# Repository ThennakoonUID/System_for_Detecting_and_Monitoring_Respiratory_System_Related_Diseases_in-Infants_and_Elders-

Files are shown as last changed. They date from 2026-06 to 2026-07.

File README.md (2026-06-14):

# VitaSync: Respiratory Disease Detection & Monitoring System

## Overview
**VitaSync** is an affordable, wearable monitoring system designed to detect and manage Chronic Respiratory Diseases (CRDs) such as Asthma, Chronic Obstructive Pulmonary Disease (COPD), and Sleep Apnea in infants and elders. Developed for the Engineering Design Project (BM1190) at the University of Moratuwa, this system shifts healthcare from reactive treatment to proactive management by providing continuous, non-invasive point-of-care data logging. 

## The Problem & Impact
Chronic Respiratory Diseases account for 12% of mortality in South Asia. Currently, early symptoms are frequently neglected in rural and low-income populations due to the centralization of high-cost diagnostic tools like hospital-grade spirometers. VitaSync addresses this critical diagnostic gap by offering a highly accessible, low-cost alternative that empowers patients and doctors to monitor conditions early and reliably.

## Key Features
* **Multiparameter Monitoring:** Continuously tracks $SpO_{2}$, heart rate, body temperature, and respiratory rate.
* **Physical Effort Tracking:** Utilizes an accelerometer to measure the physical expansion and contraction of the chest or neck to accurately log breathing rates.
* **Intelligent Analysis:** Implements a Machine Learning model to analyze raw sensor data, identify dangerous drops in oxygen levels, and detect early disease trends.
* **Mobile Dashboard:** Pairs with a mobile application to provide real-time visualization of "Respiration Status," "Oxygen Level," and "Breathing Rate" histories.
* **Emergency Alert System:** Triggers automated SMS alerts alongside real-time visual and audio warnings for necessary medical personnel or caretakers during critical events.

## Hardware Architecture
* **Microcontroller:** Low-cost ESP32-based processing unit.
* **Sensors:** High-sensitivity pulse oximetry module, heart-rate module, temperature sensor, and accelerometer.
* **Power Supply:** Rechargeable Li-Po battery system.
* **Form Factor:** Compact, battery-powered wearable wristband and chest strap ensuring patient comfort and ease of use.

## Project Team
**Team VitaSync** — Department of Electronic and Telecommunication Engineering (Biomedical Engineering), University of Moratuwa.
* Thennakoon U.I.D. (240657J)
* Pitiduwa S.M. (240518K)
* Tennekone A.D.T.M.S.H. (240642J)
* Wanninayaka W.M.I.R. (240695X)

## Hardware Architecture
* **Microcontroller:** Low-cost ESP32 or Arduino-based processing unit.
* **Sensors:** High-sensitivity pulse oximetry module, heart-rate module, temperature sensor, and accelerometer.
* **Power Supply:** Rechargeable Li-Po battery system.
* **Form Factor:** Compact, battery-powered wearable wristband and chest strap ensuring patient comfort and ease of use.

**Hardware Design Files:** [Click here to view and download the PCB design files from Google Drive](https://drive.google.com/drive/folders/1s421oYCiyX-rzGPese11IfVK0uFknzDo?usp=drive_link)

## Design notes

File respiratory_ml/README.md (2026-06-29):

# Respiratory Risk ML Model

A machine learning model that predicts whether a person is at risk of a respiratory disease by analysing SpO2 (blood oxygen saturation) and respiratory rate readings from a wearable device.

## Project overview

This model is part of the VitaSync wearable health monitoring system, built around an ESP32-WROOM-32 with a MAX30105 pulse oximeter and dual BMI160 IMUs.

The model is trained on the [BIDMC Respiratory Dataset](https://physionet.org/content/bidmc/1.0.0/) (53 ICU patients), using summary statistics extracted from 5-minute windows of SpO2 and RR readings.

## Model performance

- **Algorithm:** Logistic Regression
- **Cross-validation accuracy:** 95.3% ± 5.8%
- **Cross-validation recall:** 93.3% ± 13.3%
- **Cross-validation AUC-ROC:** 97.3% ± 5.3%
- **Training patients:** 42 | **Test patients:** 11

## Risk label definition

A patient is flagged **at risk** if any of the following are true over a 5-minute window:
- Mean SpO2 < 95%
- Minimum SpO2 < 92%
- Mean respiratory rate > 20 breaths/min
- More than 20% of RR readings outside the normal 12–20 bpm range

## Setup

1. Clone the repository
2. Create a virtual environment: `python3 -m venv venv && source venv/bin/activate`
3. Install dependencies: `pip install -r requirements.txt`
4. Run notebooks in order to reproduce the model

## Dataset

BIDMC Waveform and Physiologic Signal Collection (PhysioNet).
Raw dataset files are not included — run `01_download.ipynb` to download them.

## Disclaimer

Research prototype only. Not a certified medical device.

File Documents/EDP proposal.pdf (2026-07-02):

### Department of Electronic and Telecommunication

### Engineering

## (Biomedical Engineering)

## University of Moratuwa

# Team VitaSync

## System for Detecting and Monitoring Respiratory System Related Diseases in Infants and Elders

## Project Proposal

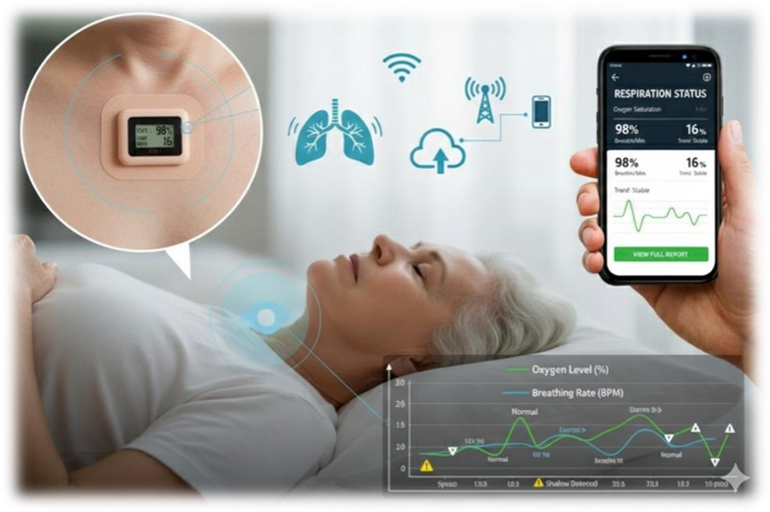
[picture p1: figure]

## Engineering Design Project – BM1190

Name | Index Number
Thennakoon U.I.D. | 240657J
Pitiduwa S.M. | 240518K
Tennekone A.D.T.M.S.H. | 240642J
Wanninayaka W.M.I.R. | 240695X

Problem Statement

Chronic Respiratory Diseases (CRDs) account for 12% of deaths in South Asia¹
. While early
detection significantly improves outcomes, a critical gap exists in accessible, low-cost diagnostic and monitoring technology. Current clinical tools are often centralized in urban hospitals, leading to the neglect of early symptoms in rural and low-income populations and resulting in preventable mortality.

Justification of Problem Selection

Selection of Chronic Respiratory Diseases (CRD) such as Chronic Obstructive Pulmonary Disease (COPD), Asthma and Sleep Apnea management in South Asia as a design focus is justified by the critical diagnostic gap that currently contributes to 12% of regional mortality

1
While these diseases are manageable if detected early, the current medical infrastructure relies heavily on centralized, high-cost diagnostic tools such as hospital grade spirometers that are inaccessible to the rural majority. This creates a technical failure where early signs are neglected not just due to a lack of awareness, but due to a lack of affordable, point-of-care monitoring technology. From an engineering perspective, there is a clear demand for a portable and affordable solution that can provide consistent, non-invasive data logging. By automating the monitoring process, a design intervention can shift the healthcare model from “reactive treatment” of the worst possible outcomes to “proactive management” during early stages, reducing the disease burden and associated productivity loss.

Proposed Solution

A wearable wrist band and chest strap powered by battery (Li-Po battery) that measures SpO2 and heart rate using a high sensitivity pulse oximetry and heart-rate module along with respiratory rate/breathing effort using an accelerometer and temperature using a temperature sensing module. Different respiratory diseases such as Asthma, COPD and sleep apnea show different levels of drops in Oxygen. Respiratory rate is tracked by measuring the physical expansion and contraction of the chest or neck. Raw data is collected using these sensors using a relatively low cost ESP32 or Arduino-based system. A Machine Learning model is then implemented to analyze the data, detect trends and alert the necessary personnel via an emergency SMS alert and real time visual and audio warnings. System should be implemented using low cost hardware and compact ensuring ease of use.

References

[1] World Health Organization - Chronic respiratory diseases in WHO South-East Asia – World Health Organization[Online] - Chronic respiratory diseases in WHO South-East Asia.pdf (https://knowledge-action-portal.com/sites/default/files/2025-09/Chronic%20respiratory%20diseases%20in%20WHO%20South-East%20Asia.pdf)

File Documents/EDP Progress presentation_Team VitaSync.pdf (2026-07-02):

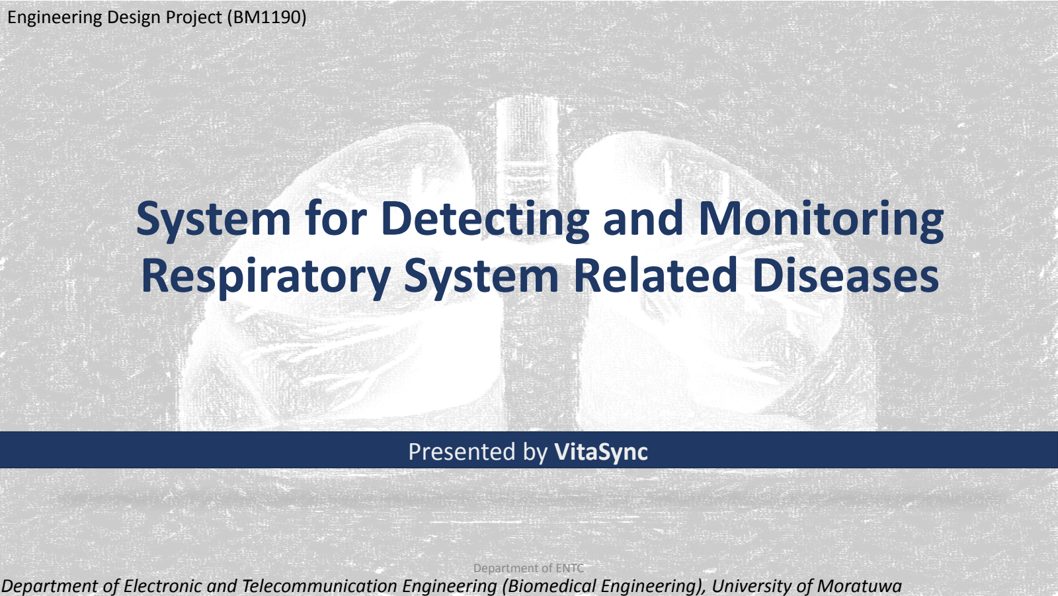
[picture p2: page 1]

# System for Detecting and Monitoring Respiratory System Related Diseases

Department of Electronic and Telecommunication Engineering (Biomedical Engineering), University of Moratuwa

## Presented by VitaSync

Engineering Design Project (BM1190)

Department of ENTC

# Team Members

U.I.D. Thennakoon

S.M. Pitiduwa

A.D.T.M.S.H. Tennekone

W.M.I.R. Wanninayaka

240518K

240657J

240642J

240695X

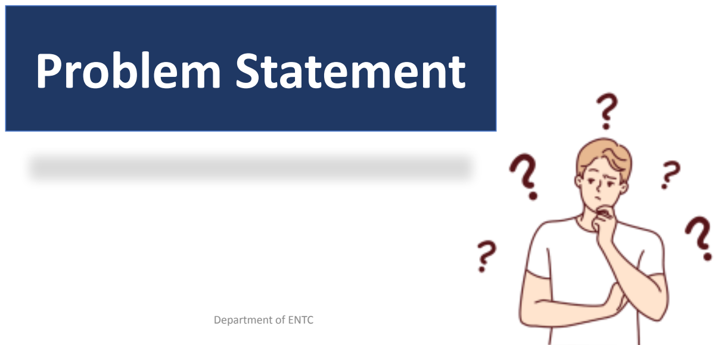
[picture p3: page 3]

# Problem Statement

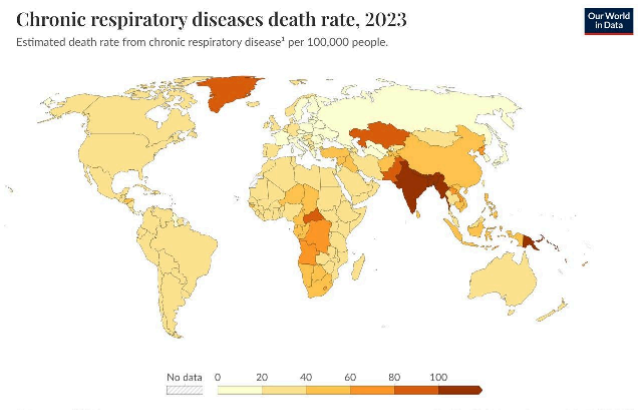
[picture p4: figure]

- The Statistic: Chronic respiratory diseases (CRDs) – primarily chronic obstructive pulmonary disease (COPD) and asthma – are a major and growing public health challenge in the WHO South-East Asia Region, responsible for nearly 12% of all deaths WHO Link
- The Gap: A critical lack of accessible, low-cost diagnostic and monitoring
technology.
- The Constraint: Current tools are centralized in urban hospitals, leading to the neglect of early
symptoms in rural populations

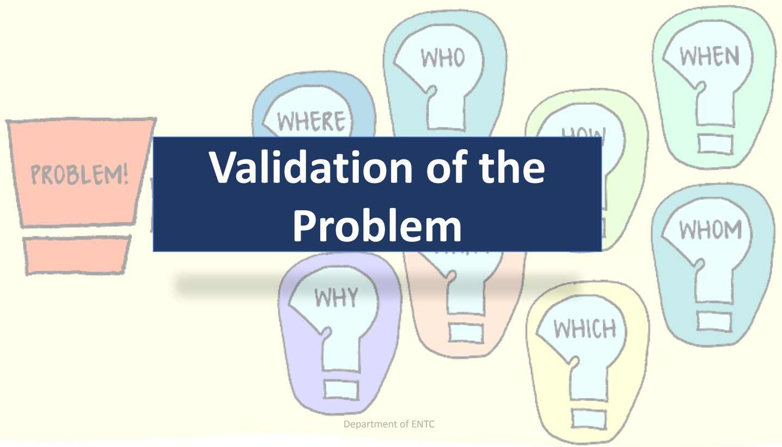
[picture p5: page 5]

# Validation of the Problem

Evidence: Hospital-grade spirometers are high-cost and inaccessible to the rural majority.

Technical Failure: Early signs are missed not just due to lack of awareness, but due to a lack of

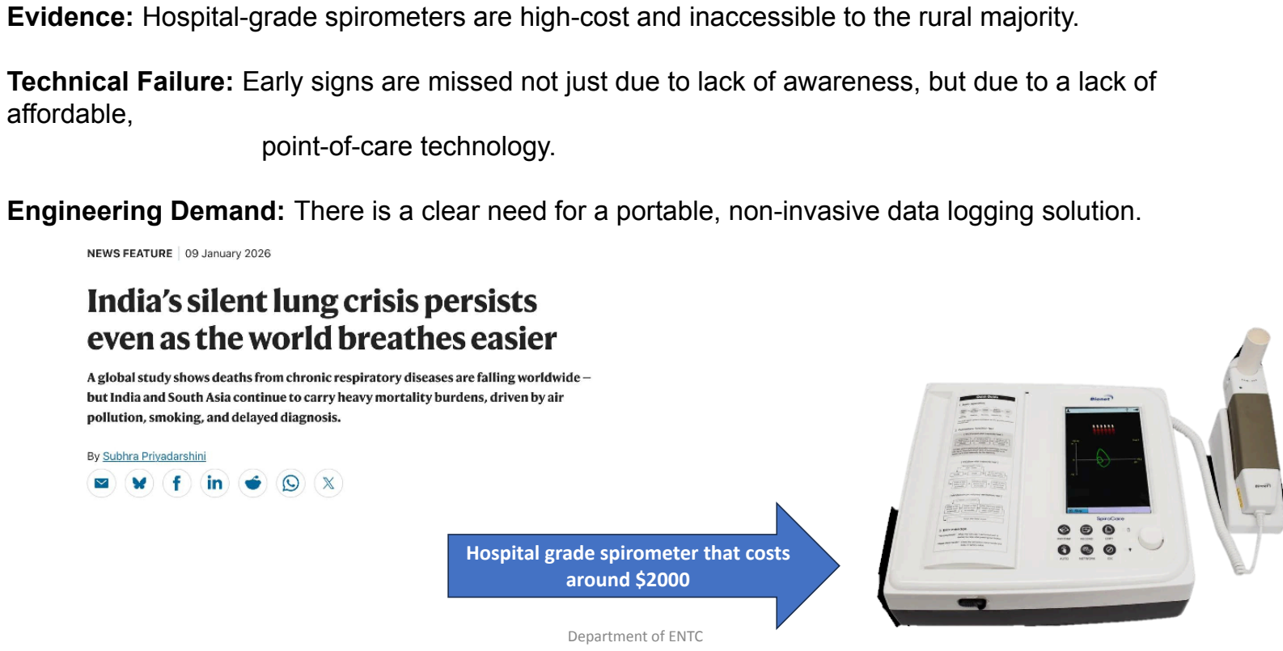
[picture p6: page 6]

affordable,
point-of-care technology.

Engineering Demand: There is a clear need for a portable, non-invasive data logging solution.

Hospital grade spirometer that costs around $2000

- Discussed the need for a non-invasive monitoring device with multiple resource personnel associated with the medical field.
- Dr. Sanjeewa Tennekone - Consultant Neonatologist - 0773645577
- Dr. Dilrukshi Maheshika - Consultant Rheumatologist - 0773417558
- Dr. P.L.B.Nishantha - MO Cardiothoracic - 0776552891
- Dr. Dammika Fernando - MO Radiology - 0777499150
- Dr. S.A.P.L.Nanayakkara - 0772619993

# Our Solution

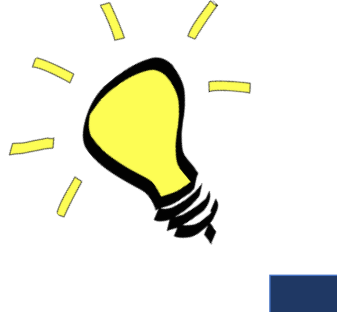
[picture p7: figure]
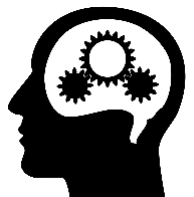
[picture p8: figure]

PCB

Breathing pattern
identification using MPU 5060 three axis accelerometer

SPO2 level and BPM
MAX30102 readings

ML model
trained
using
existing
datasets
Power

Notification if disease is detected or not

Probability of disease

Physical indicators

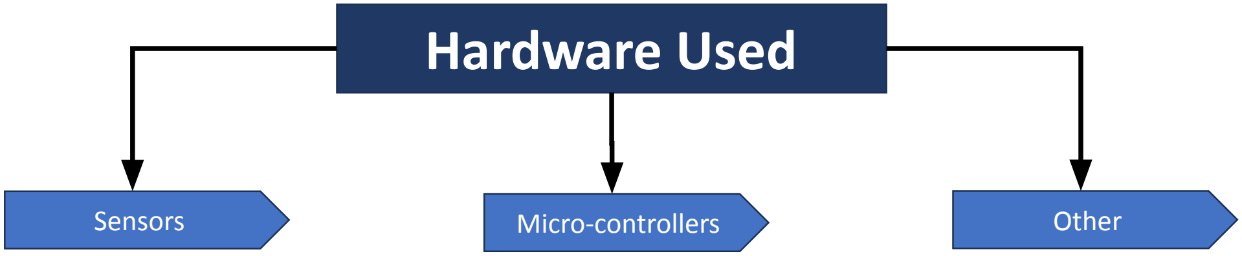
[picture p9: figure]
Hardware Used; Sensors; Micro-controllers; Other
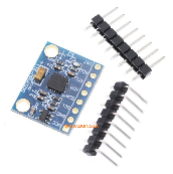
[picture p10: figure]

MAX30102

MPU 6050 3-Axis
Accelerometer

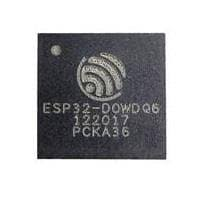
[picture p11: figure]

Resistors
Capacitors
Voltage regulators
DC-DC Boost converters
Charging modules

ATmega328P-AU

ESP32 DOWDQ6
(To run the ML model)

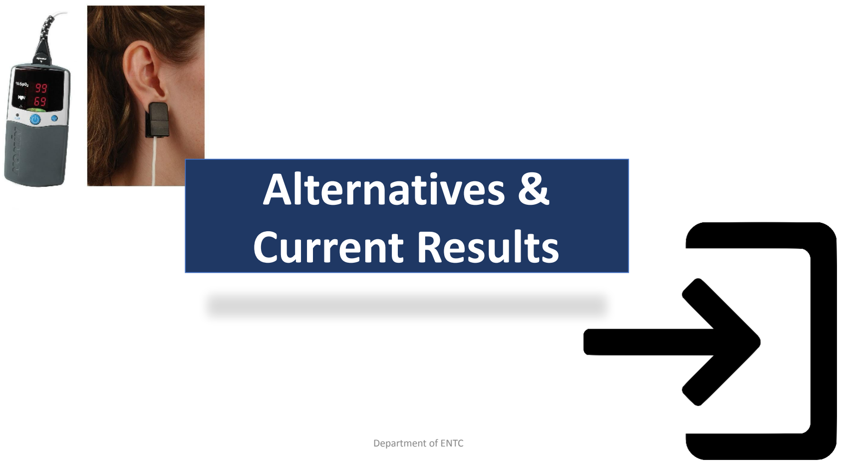
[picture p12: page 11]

# Alternatives & Current Results

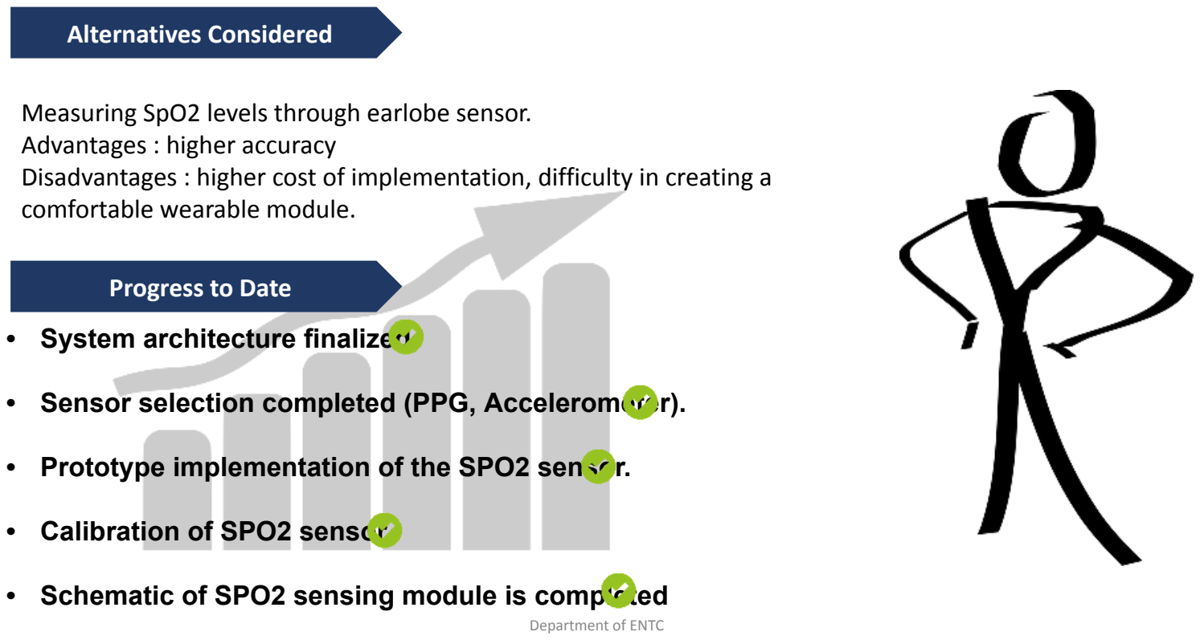
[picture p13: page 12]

Measuring SpO2 levels through earlobe sensor.
Advantages : higher accuracy
Disadvantages : higher cost of implementation, difficulty in creating a comfortable wearable module.
- System architecture finalized.
- Sensor selection completed (PPG, Accelerometer).
- Prototype implementation of the SPO2 sensor.
- Calibration of SPO2 sensor.

## - Schematic of SPO2 sensing module is completed

Progress to Date

Alternatives Considered

# Challenges & Overcoming Them

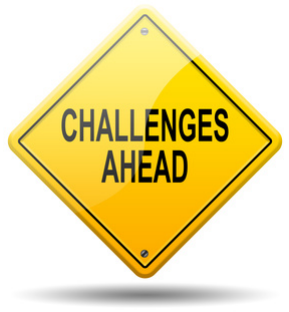
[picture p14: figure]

Problem | Current solution
Amount of noise due to the distances from the sensor modules to the control unit and other noise related to the sensors are high. | Use a cable that can transmit sensor readings with less accumulation of noise (shielded 4-core wire). However, wearbility issues might occur. Use digital filtering methods.
Creating enclosures for sensor modules that are comfortable to wear for users. | Use stretchable and elastic-like materials that are easy to wear.
Collecting data to train a ML model. | Use existing datasets that can be found on the internet.
Obtaining accurate readings from sensors. | Calibrate the sensors properly use digital filtering methods to remove noise.
Displaying the data and predictions to users. | Create a simple dashboard that can display readings and user information.

# Thank you !

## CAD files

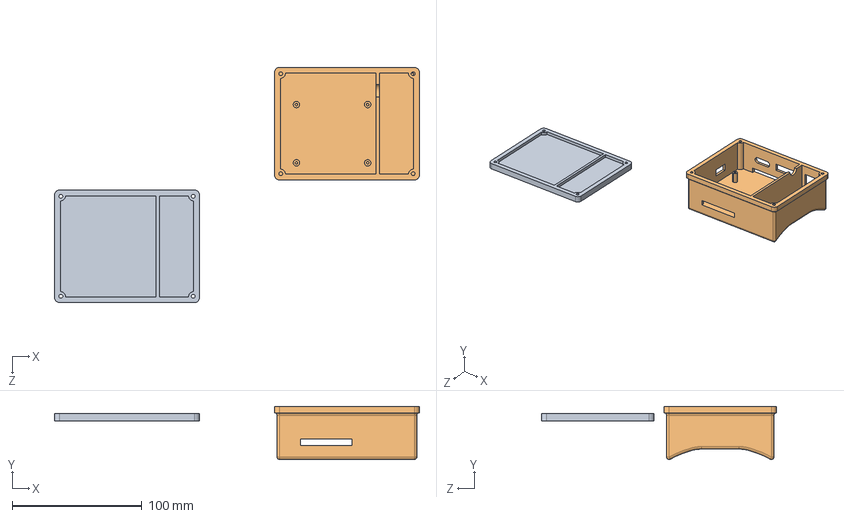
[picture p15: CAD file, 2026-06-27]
Enclosures/STEP_files/Shoulder_Assembly.STEP
281.8 x 41.1 x 181.6 mm
lid
part final

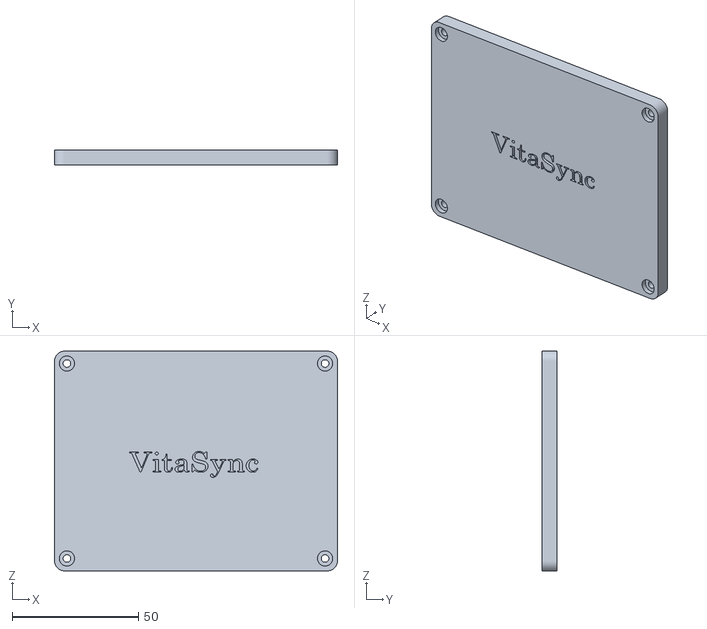
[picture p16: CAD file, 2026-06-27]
Enclosures/STL_files/Shoulder_Assembly - Lid-1.STL
112.0 x 6.00 x 87.0

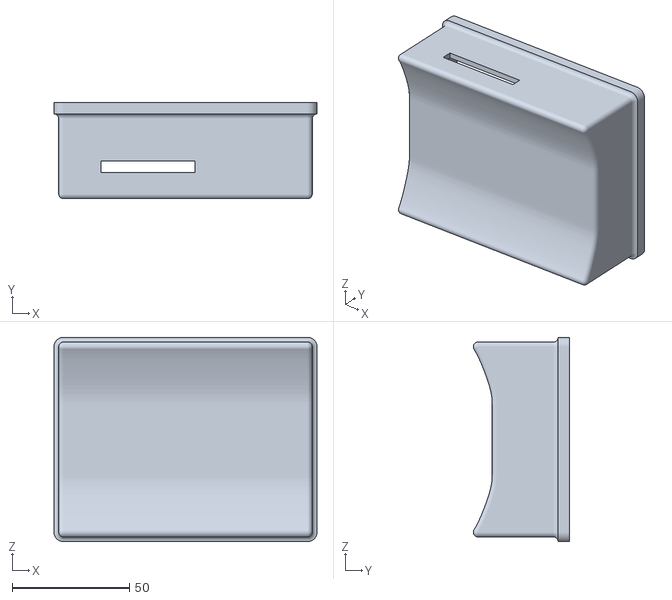
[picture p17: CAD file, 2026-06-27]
Enclosures/STL_files/Shoulder_Assembly - Enclosure.STL
112.0 x 41.1 x 87.0

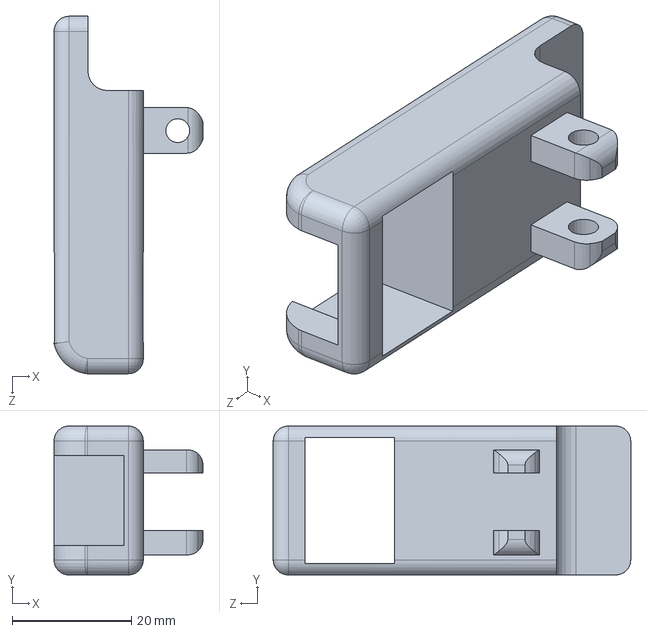
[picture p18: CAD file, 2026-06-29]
Enclosures/Solidworks_part_files/finger tip bellow part.SLDPRT
25.0 x 25.0 x 60.0 mm

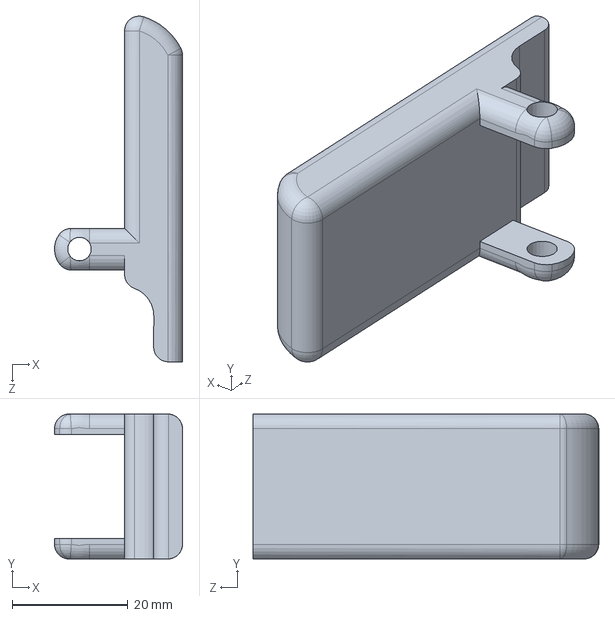
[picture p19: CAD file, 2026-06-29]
Enclosures/Solidworks_part_files/finger tip upper part.SLDPRT
22.1 x 25.0 x 59.6 mm

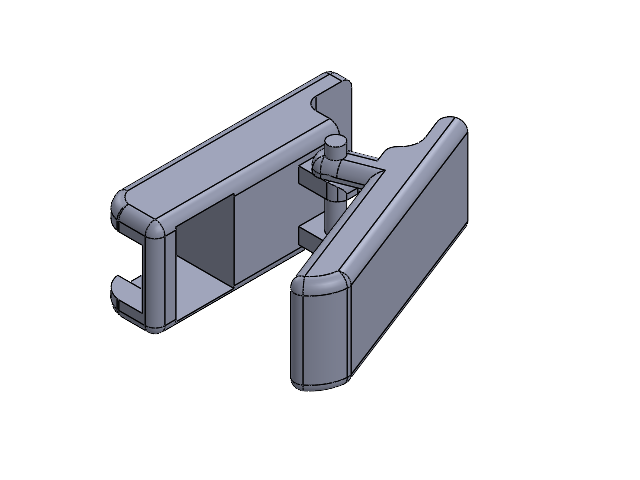
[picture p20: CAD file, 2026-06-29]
Enclosures/Assembly_files/Fingertip_Assembly.SLDASM
bellow part
nut

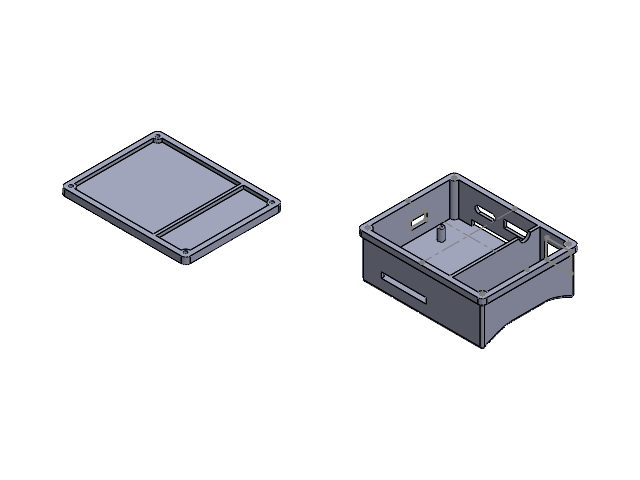
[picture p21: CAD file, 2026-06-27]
Enclosures/Assembly_files/Shoulder_Assembly.SLDASM
lid
part final

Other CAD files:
Enclosures/Solidworks_part_files/Lid.SLDPRT
Enclosures/Solidworks_part_files/Enclosure.SLDPRT

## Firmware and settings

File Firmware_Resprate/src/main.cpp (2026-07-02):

#include <Arduino.h>
#include <Wire.h>
#include <DFRobot_BMI160.h>
#include <WiFi.h>
#include <FirebaseESP32.h>
#include <esp_task_wdt.h>

// =============================================================
//  WIFI & FIREBASE CONFIGURATION
// =============================================================
#define WIFI_SSID "Your WiFi SSID"
#define WIFI_PASSWORD "Your WiFi Password"

#define FIREBASE_HOST "respiratory-system-monitor-default-rtdb.firebaseio.com"
#define FIREBASE_AUTH "Firebase Database Secret or API Key"

FirebaseData fbdo;
FirebaseAuth auth;
FirebaseConfig config;
TaskHandle_t FirebaseTaskHandle;

// =============================================================
//  SENSOR CONFIGURATION
// =============================================================
#define I2C_SDA 21
#define I2C_SCL 22

#define ADDR_CHEST 0x68 // Primary Abdomen Sensor
#define ADDR_BACK  0x69 // Reference Back Sensor

#define SAMPLE_RATE_HZ  25
#define SAMPLE_INTERVAL (1000 / SAMPLE_RATE_HZ)

// ── Motion Gating ─────────────────────────────────────────
#define MOTION_THRESHOLD  800.0f 
#define MOTION_LOCKOUT_MS 3000

#define PRINT_INTERVAL    1000

// CRITICAL FIX: Turn off 25Hz raw data printing to prevent UART overflow
// and garbled text while running standalone over WiFi.
#define ENABLE_TELEPLOT   0 

// =============================================================
//  POWER / WIFI STABILITY SETTINGS
// =============================================================
// If your PCB power rail cannot supply full peak current, lowering
// TX power reduces current spikes that cause brownout resets.
// 0 = auto/full power (try this first once hardware power is fixed),
// or use WIFI_POWER_15dBm / WIFI_POWER_11dBm to cut peak draw.
#define REDUCE_WIFI_TX_POWER 1

#define WIFI_RECONNECT_INTERVAL_MS 5000
#define FIREBASE_RETRY_INTERVAL_MS 3000

// How often the status fields (state, progress %, uptime, etc.) get pushed
// to Firebase. Kept separate from the 2s rate/motion upload cadence since
// status changes less often and we don't want to spam the DB.
#define STATUS_UPLOAD_INTERVAL_MS 2000

// =============================================================
//  SYSTEM STATUS TRACKING (for Firebase progress reporting)
// =============================================================
enum SystemState {
  STATE_BOOTING,           // setup() running
  STATE_WIFI_CONNECTING,   // waiting for WiFi
  STATE_SENSOR_INIT,       // initializing BMI160s
  STATE_SENSOR_FAILED,     // sensor init failed, retrying in background
  STATE_GATHERING_WINDOW,  // running, peak-detection buffer still filling
  STATE_RUNNING,           // fully operational, RR values valid
  STATE_MOTION_GATED       // running but currently motion-gated
};

const char* stateToString(SystemState s) {
  switch (s) {
    case STATE_BOOTING:          return "booting";
    case STATE_WIFI_CONNECTING:  return "wifi_connecting";
    case STATE_SENSOR_INIT:      return "sensor_init";
    case STATE_SENSOR_FAILED:    return "sensor_failed";
    case STATE_GATHERING_WINDOW: return "gathering_window";
    case STATE_RUNNING:          return "running";
    case STATE_MOTION_GATED:     return "motion_gated";
    default:                     return "unknown";
  }
}

volatile SystemState systemState = STATE_BOOTING;
volatile int windowProgressPercent = 0; // 0-100, how full the RR peak-detection buffer is

// =============================================================
//  BIQUAD STRUCT (Base element for filters)
// =============================================================
struct Biquad {
  float b0, b1, b2, a1, a2;
  float x1 = 0, x2 = 0, y1 = 0, y2 = 0;
  
  Biquad(float _b0, float _b1, float _b2, float _a1, float _a2)
      : b0(_b0), b1(_b1), b2(_b2), a1(_a1), a2(_a2) {}

  float process(float x) {
    float y = b0*x + b1*x1 + b2*x2 - a1*y1 - a2*y2;
    x2 = x1; x1 = x;
    y2 = y1; y1 = y;
    return y;
  }
  void reset() { x1=x2=y1=y2=0; }
};

// =============================================================
//  STAGE 1: 6th-Order Butterworth BP + Notch + Savitzky-Golay
// =============================================================
struct BPFilter6 {
  Biquad s1 = Biquad( 0.00057f,  0.00000f, -0.00057f, -1.98942f,  0.98944f);
  Biquad s2 = Biquad( 0.00057f,  0.00000f, -0.00057f, -1.97128f,  0.97290f);
  Biquad s3 = Biquad( 0.00057f,  0.00000f, -0.00057f, -1.95524f,  0.95810f);
  
  float process(float x) { return s3.process(s2.process(s1.process(x))); }
  void reset() { s1.reset(); s2.reset(); s3.reset(); }
};

struct NotchFilter1Hz {
  Biquad s1 = Biquad( 0.97546f, -1.89505f,  0.97546f, -1.89505f,  0.95091f);
  float process(float x) { return s1.process(x); }
  void reset() { s1.reset(); }
};

constexpr int SG_WIN = 11;
constexpr float SG_COEF[SG_WIN] = {
    -0.09090909f,  0.06060606f,  0.16883117f,  0.23376623f,  0.25541126f,
     0.23376623f,  0.16883117f,  0.06060606f, -0.09090909f, -0.06060606f,
    -0.09090909f
};

struct SavitzkyGolay {
  static const int WIN = SG_WIN;
  float buf[WIN] = {};
  int   head = 0;
  int   filled = 0;
  
  float process(float x) {
    buf[head] = x;
    head = (head + 1) % WIN;
    if (filled < WIN) { filled++; }
    if (filled < WIN) return x; 

    float out = 0.0f;
    for (int i = 0; i < WIN; i++) {
      int idx = (head + i) % WIN; 
      out += SG_COEF[i] * buf[idx];
    }
    return out;
  }

  void reset() {
    for (int i = 0; i < WIN; i++) buf[i] = 0;
    head = 0; filled = 0;
  }
};

// =============================================================
//  STAGE 2: Time-Domain Peak Detection (Sliding Window)
// =============================================================
struct PeakDetectionRR {
  static const int BUF_LEN      = 300; 
  static const int UPDATE_EVERY = 25; 
  static const int MIN_DIST     = 20; 

  float buf[BUF_LEN] = {};
  int   head = 0;
  bool  full = false;
  int   samplesSinceUpdate = 0;
  float lastRR = 0.0f;

  void push(float v) {
    buf[head] = v;
    head = (head + 1) % BUF_LEN;
    if (!full && head == 0) full = true;
    samplesSinceUpdate++;
  }

  float compute() {
    if (!full) return 0.0f; 
    if (samplesSinceUpdate < UPDATE_EVERY) return lastRR; 
    
    samplesSinceUpdate = 0; 

    float win[BUF_LEN];
    float mean = 0;
    for (int i = 0; i < BUF_LEN; i++) {
      win[i] = buf[(head + i) % BUF_LEN];
      mean += win[i];
    }
    mean /= BUF_LEN; 

    int peakIndices[50]; 
    int peakCount = 0;
    
    for (int i = 1; i < BUF_LEN - 1; i++) {
      if (win[i] > win[i - 1] && win[i] > win[i + 1] && win[i] > mean) {
        if (peakCount == 0 || (i - peakIndices[peakCount - 1]) >= MIN_DIST) {
          peakIndices[peakCount++] = i;
          if (peakCount >= 50) break; 
        } 
        else if (win[i] > win[peakIndices[peakCount - 1]]) {
          peakIndices[peakCount - 1] = i;
        }
      }
    }

    if (peakCount >= 2) {
      float totalIntervals = 0;
      for (int i = 1; i < peakCount; i++) {
        totalIntervals += (peakIndices[i] - peakIndices[i - 1]);
      }
      
      float avgIntervalSamples = totalIntervals / (peakCount - 1);
      float avgIntervalSeconds = avgIntervalSamples / (float)SAMPLE_RATE_HZ; 
      float newRR = 60.0f / avgIntervalSeconds;
      
      if (newRR >= 4.0f && newRR <= 60.0f) {
         lastRR = (lastRR == 0.0f) ? newRR : (0.4f * newRR + 0.6f * lastRR);
      }
    }
    return lastRR;
  }

  void reset() {
    for (int i = 0; i < BUF_LEN; i++) buf[i] = 0;
    head = 0; full = false; samplesSinceUpdate = 0; lastRR = 0;
  }
};

// =============================================================
//  MEDIAN FILTER
// =============================================================
struct MedianFilter {
  static const int SZ = 9;
  float buf[SZ] = {};
  int   idx = 0;

  float process(float v) {
    buf[idx] = v;
    idx = (idx + 1) % SZ;
    float s[SZ];
    for (int i = 0; i < SZ; i++) s[i] = buf[i];
    for (int i = 1; i < SZ; i++) {
      float key = s[i];
      int j = i - 1;
      while (j >= 0 && s[j] > key) { s[j+1] = s[j]; j--; }
      s[j+1] = key;
    }
    return s[SZ / 2];
  }
};

// =============================================================
//  MULTI-AXIS DIFFERENTIAL FUSION
// =============================================================
struct AxisFuser {
  static const int WIN = 50;
  float buf[WIN] = {};
  int   idx = 0;
  bool  full = false;
  float variance = 0;
  
  void push(float v) {
    buf[idx] = v;
    idx = (idx + 1) % WIN;
    if (idx == 0) full = true;
    int n = full ? WIN : idx;
    if (n < 2) { variance = 0; return; }
    float mean = 0;
    for (int i = 0; i < n; i++) mean += buf[i];
    mean /= n;
    float var = 0;
    for (int i = 0; i < n; i++) var += (buf[i]-mean)*(buf[i]-mean);
    variance = var / n;
  }
};

float fusedDiff(float dx, float dy, float dz, float vx, float vy, float vz) {
  float total = vx + vy + vz;
  if (total < 1e-9f) return (dx + dy + dz) / 3.0f;  
  return (dx*vx + dy*vy + dz*vz) / total;
}

// =============================================================
//  GLOBALS & INSTANCES
// =============================================================
DFRobot_BMI160 bmi_chest, bmi_back;
bool bmiReady = false;

MedianFilter    med_cx, med_cy, med_cz;   
MedianFilter    med_bx, med_by, med_bz;
BPFilter6       bp_cx, bp_cy, bp_cz;
BPFilter6       bp_bx, bp_by, bp_bz;
NotchFilter1Hz  notch;
SavitzkyGolay   sgSmooth;            
PeakDetectionRR pdRR; 

AxisFuser fuser_cx, fuser_cy, fuser_cz;
AxisFuser fuser_bx, fuser_by, fuser_bz;

volatile float respiratoryRate  = 0.0f;
volatile bool  motionGated    = false;

unsigned long lastMotionTime = 0;
unsigned long lastRRSample   = 0;
unsigned long lastPrint      = 0;

// WiFi/Firebase state tracking (non-blocking)
volatile bool wifiWasConnected = false;
unsigned long lastWifiAttempt = 0;
bool firebaseConfigured = false;

// =============================================================
//  WIFI EVENT HANDLER (event-driven, no blocking loops)
// =============================================================
void onWifiEvent(WiFiEvent_t event) {
  switch (event) {
    case ARDUINO_EVENT_WIFI_STA_CONNECTED:
      Serial.println("[WiFi] Connected to AP.");
      break;
    case ARDUINO_EVENT_WIFI_STA_GOT_IP:
      Serial.print("[WiFi] Got IP: ");
      Serial.println(WiFi.localIP());
      wifiWasConnected = true;
      break;
    case ARDUINO_EVENT_WIFI_STA_DISCONNECTED:
      Serial.println("[WiFi] Disconnected. Will retry in background.");
      wifiWasConnected = false;
      break;
    default:
      break;
  }
}

// Call periodically from loop() — non-blocking reconnect attempt.
void maintainWifi() {
  if (WiFi.status() == WL_CONNECTED) return;
  unsigned long now = millis();
  if (now - lastWifiAttempt < WIFI_RECONNECT_INTERVAL_MS) return;
  lastWifiAttempt = now;
  Serial.println("[WiFi] Attempting reconnect...");
  WiFi.disconnect();
  WiFi.begin(WIFI_SSID, WIFI_PASSWORD);
}

// =============================================================
//  CORE 0: FIREBASE UPLOAD TASK (STANDALONE PROOF)
// =============================================================
void firebaseUploadTask(void *pvParameters) {
  esp_task_wdt_add(NULL); // register this task with the watchdog
  unsigned long lastStatusUpload = 0;

  for (;;) {
    esp_task_wdt_reset();

    // Only upload if properly connected and authenticated.
    // This never blocks the sensor loop on core 1.
    if (WiFi.status() == WL_CONNECTED && Firebase.ready()) {
      bool ok1 = Firebase.setFloat(fbdo, "/respiratory_data/rate", respiratoryRate);
      esp_task_wdt_reset(); // feed the watchdog immediately after this blocking call
      if (!ok1) {
        Serial.print("[Firebase] setFloat failed: ");
        Serial.println(fbdo.errorReason());
      }

      bool ok2 = Firebase.setBool(fbdo, "/respiratory_data/motion_gated", motionGated);
      esp_task_wdt_reset(); // feed the watchdog immediately after this blocking call
      if (!ok2) {
        Serial.print("[Firebase] setBool failed: ");
        Serial.println(fbdo.errorReason());
      }

      // Status/progress fields — uploaded less frequently since they
      // change slower than rate/motion, to keep this loop iteration short.
      unsigned long now = millis();
      if (now - lastStatusUpload >= STATUS_UPLOAD_INTERVAL_MS) {
        lastStatusUpload = now;

        Firebase.setString(fbdo, "/respiratory_data/status/state", stateToString(systemState));
        esp_task_wdt_reset();

        Firebase.setInt(fbdo, "/respiratory_data/status/window_progress_percent", windowProgressPercent);
        esp_task_wdt_reset();

        Firebase.setBool(fbdo, "/respiratory_data/status/wifi_connected", WiFi.status() == WL_CONNECTED);
        esp_task_wdt_reset();

        Firebase.setBool(fbdo, "/respiratory_data/status/sensors_ready", bmiReady);
        esp_task_wdt_reset();

        Firebase.setInt(fbdo, "/respiratory_data/status/uptime_seconds", (int)(millis() / 1000));
        esp_task_wdt_reset();

        Firebase.setInt(fbdo, "/respiratory_data/status/wifi_rssi", WiFi.status() == WL_CONNECTED ? WiFi.RSSI() : 0);
        esp_task_wdt_reset();
      }
    }

    // Generous delay prevents WDT crash and network stack overflow
    vTaskDelay(pdMS_TO_TICKS(2000));
  }
}

// =============================================================
//  UPDATE BMI160
// =============================================================
void updateBMI160() {
  unsigned long now = millis();
  if (now - lastRRSample < SAMPLE_INTERVAL) return;
  lastRRSample = now;

  int16_t dc[6] = {}, db[6] = {};
  if (bmi_chest.getAccelGyroData(dc) != 0) return;
  if (bmi_back.getAccelGyroData(db)  != 0) return;
  
  float cxr = (dc[3]/16384.0f) * 1000.0f;
  float cyr = (dc[4]/16384.0f) * 1000.0f;
  float czr = (dc[5]/16384.0f) * 1000.0f;
  
  float bxr = (db[3]/16384.0f) * 1000.0f;
  float byr = (db[4]/16384.0f) * 1000.0f;
  float bzr = (db[5]/16384.0f) * 1000.0f;

  float cx_g = cxr/1000.0f; float cy_g = cyr/1000.0f; float cz_g = czr/1000.0f;
  float bx_g = bxr/1000.0f; float by_g = byr/1000.0f; float bz_g = bzr/1000.0f;

  float magChest = sqrtf(cx_g*cx_g + cy_g*cy_g + cz_g*cz_g);
  float magBack  = sqrtf(bx_g*bx_g + by_g*by_g + bz_g*bz_g);
  
  if (magChest < 0.1f || magBack < 0.1f) return;

  float instMotionChest = fabsf(magChest - 1.0f) * 1000.0f;
  float instMotionBack  = fabsf(magBack - 1.0f) * 1000.0f;
  float motionMag = fmaxf(instMotionChest, instMotionBack);
  
  if (motionMag > MOTION_THRESHOLD) {
    motionGated = true; lastMotionTime = now;
    bp_cx.reset(); bp_cy.reset(); bp_cz.reset();
    bp_bx.reset(); bp_by.reset(); bp_bz.reset();
    notch.reset(); sgSmooth.reset(); pdRR.reset();
  }
  
  if (motionGated && now - lastMotionTime > MOTION_LOCKOUT_MS) motionGated = false;
  
  float cx = med_cx.process(cxr), cy = med_cy.process(cyr), cz = med_cz.process(czr);
  float bx = med_bx.process(bxr), by = med_by.process(byr), bz = med_bz.process(bzr);
  
  float fcx = bp_cx.process(cx), fcy = bp_cy.process(cy), fcz = bp_cz.process(cz);
  float fbx = bp_bx.process(bx), fby = bp_by.process(by), fbz = bp_bz.process(bz);
  
  float dx = fcx - fbx, dy = fcy - fby, dz = fcz - fbz;
  fuser_cx.push(fcx); fuser_cy.push(fcy); fuser_cz.push(fcz);
  fuser_bx.push(fbx); fuser_by.push(fby); fuser_bz.push(fbz);

  float vx = (fuser_cx.variance + fuser_bx.variance);
  float vy = (fuser_cy.variance + fuser_by.variance);
  float vz = (fuser_cz.variance + fuser_bz.variance);
  
  float diff_fused = fusedDiff(dx, dy, dz, vx, vy, vz);
  
  float notched = notch.process(diff_fused);
  float sig     = sgSmooth.process(notched);
  
  if (!motionGated) {
    pdRR.push(sig);
    float rr = pdRR.compute();
    if (rr > 0) respiratoryRate = rr;
  }

  // ── Status tracking for Firebase progress reporting ──
  if (motionGated) {
    systemState = STATE_MOTION_GATED;
  } else if (!pdRR.full) {
    systemState = STATE_GATHERING_WINDOW;
    windowProgressPercent = (pdRR.samplesSinceUpdate * 100) / PeakDetectionRR::BUF_LEN;
  } else {
    systemState = STATE_RUNNING;
    windowProgressPercent = 100;
  }

#if ENABLE_TELEPLOT
  Serial.print(">SigFused_mg:");  Serial.println(sig, 2);
  Serial.print(">Motion_mg:");    Serial.println(motionMag, 1);
  Serial.print(">Gated:");        Serial.println(motionGated ? 10 : 0);
  Serial.print(">RespRate:");     Serial.println(respiratoryRate, 1);
#endif
}

void printStatus() {
  if (millis() - lastPrint < PRINT_INTERVAL) return;
  lastPrint = millis();

  Serial.print("State=");
  Serial.print(stateToString(systemState));
  Serial.print(" Progress=");
  Serial.print(windowProgressPercent);
  Serial.println("%");

  Serial.print("RespRate=");
  if (!pdRR.full) {
    int percent = (pdRR.samplesSinceUpdate * 100) / PeakDetectionRR::BUF_LEN;
    Serial.print("Gathering window ("); Serial.print(percent); Serial.println("%)");
  } else {
    Serial.print(respiratoryRate, 1); Serial.println(" br/min");
  }
  Serial.print("WiFi=");
  Serial.println(WiFi.status() == WL_CONNECTED ? "connected" : "DISCONNECTED");
}

// =============================================================
//  SETUP
// =============================================================
void setup() {
  Serial.begin(115200);
  delay(1500); // let power rails stabilize before WiFi radio init (helps with brownout on marginal supplies)
  Serial.println("\nBooting Standalone System...");
  systemState = STATE_BOOTING;

  // Configure watchdog for the whole app. 20s gives headroom for a slow
  // Firebase/SSL call (bounded to ~4s read timeout, see setup() below)
  // plus WiFi reconnect attempts, without masking a genuine hang.
  esp_task_wdt_init(20, true);

  // 1. Initialize Wi-Fi (event-driven, non-blocking after this point)
  systemState = STATE_WIFI_CONNECTING;
  WiFi.onEvent(onWifiEvent);
  WiFi.mode(WIFI_STA);
  WiFi.setAutoReconnect(true);
  WiFi.persistent(false); // avoid unnecessary flash writes on every connect

#if REDUCE_WIFI_TX_POWER
  // Lowering TX power reduces peak current draw, which helps a lot if the
  // 3.3V rail is marginal. Remove/raise this once hardware power is solid.
  WiFi.begin(WIFI_SSID, WIFI_PASSWORD);
  WiFi.setTxPower(WIFI_POWER_15dBm);
#else
  WiFi.begin(WIFI_SSID, WIFI_PASSWORD);
#endif

  // Short bounded wait just so first boot has a chance to come up before
  // we start sensors — but we DO NOT hang forever like the old code did.
  unsigned long wifiStart = millis();
  while (WiFi.status() != WL_CONNECTED && millis() - wifiStart < 8000) {
    delay(250);
    Serial.print(".");
  }
  Serial.println();
  if (WiFi.status() == WL_CONNECTED) {
    Serial.println("Wi-Fi connected on boot.");
  } else {
    Serial.println("Wi-Fi not yet connected — will keep retrying in background.");
  }

  // 2. Initialize Firebase
  fbdo.setBSSLBufferSize(1024, 512); // CRITICAL FIX: Optimize SSL memory
  config.database_url = FIREBASE_HOST;
  config.signer.tokens.legacy_token = FIREBASE_AUTH;
  Firebase.reconnectWiFi(true);

  // Bound how long a single Firebase call is allowed to block. Without this,
  // a stalled SSL handshake or slow network can block setFloat()/setBool()
  // for far longer than the task watchdog timeout and trigger a reboot.
  fbdo.setResponseSize(1024);
  Firebase.setReadTimeout(fbdo, 4000);        // ms
  Firebase.setwriteSizeLimit(fbdo, "tiny");   // small payloads, no need for large limit

  Firebase.begin(&config, &auth);
  firebaseConfigured = true;

  // 3. Start Dual Core Task for Firebase Uploads
  xTaskCreatePinnedToCore(
    firebaseUploadTask,   
    "FirebaseTask",       
    8192,                 
    NULL,                 
    1,                    
    &FirebaseTaskHandle,  
    0);                   

  // 4. Initialize Sensors
  systemState = STATE_SENSOR_INIT;
  Wire.begin(I2C_SDA, I2C_SCL);
  Wire.setClock(400000);

  bool sensorsOk = true;
  if (bmi_chest.softReset() != BMI160_OK) { Serial.println("Chest sensor soft reset failed"); sensorsOk = false; }
  delay(100);
  if (sensorsOk && bmi_chest.I2cInit(ADDR_CHEST) != BMI160_OK) { Serial.println("Chest sensor init failed"); sensorsOk = false; }

  delay(100);

  if (sensorsOk && bmi_back.softReset() != BMI160_OK) { Serial.println("Back sensor soft reset failed"); sensorsOk = false; }
  delay(100);
  if (sensorsOk && bmi_back.I2cInit(ADDR_BACK) != BMI160_OK) { Serial.println("Back sensor init failed"); sensorsOk = false; }

  bmiReady = sensorsOk;
  if (!bmiReady) {
    // Don't hard-lock the MCU (while(1)) — that made the whole board
    // unrecoverable without a manual reset. Instead keep WiFi/Firebase
    // alive and keep retrying sensor init in the background.
    systemState = STATE_SENSOR_FAILED;
    Serial.println("Sensors not ready — will retry periodically in loop().");
  } else {
    systemState = STATE_GATHERING_WINDOW;
    Serial.println("System Processing Running Standalone.");
  }
}

// =============================================================
//  LOOP
// =============================================================
unsigned long lastSensorRetry = 0;

void loop() {
  maintainWifi(); // non-blocking reconnect if WiFi dropped

  if (bmiReady) {
    updateBMI160();
  } else {
    systemState = STATE_SENSOR_FAILED;
    // Retry sensor init every 5s without blocking WiFi/Firebase
    unsigned long now = millis();
    if (now - lastSensorRetry > 5000) {
      lastSensorRetry = now;
      Serial.println("Retrying BMI160 init...");
      bool ok = (bmi_chest.softReset() == BMI160_OK) &&
                (bmi_chest.I2cInit(ADDR_CHEST) == BMI160_OK) &&
                (bmi_back.softReset() == BMI160_OK) &&
                (bmi_back.I2cInit(ADDR_BACK) == BMI160_OK);
      bmiReady = ok;
      if (ok) {
        Serial.println("Sensors recovered.");
        systemState = STATE_GATHERING_WINDOW;
      }
    }
  }

  printStatus();
}

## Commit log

2026-06-27 Enclosure designs
    Solidworks files for the shoulder enclosure. Includes solidworks parts files, step files, stl files and assembly files.
    [Enclosure.SLDPRT, Lid.SLDPRT, Shoulder_Assembly - Enclosure.STL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]
2026-06-27 enclosure of finger tip
    This comprises the fingertip assembly, including the upper and lower housing components
    [Fingertip_Assembly.SLDASM, finger tip bellow part.SLDPRT, finger tip upper part.SLDPRT]
2026-06-29 Machine learning model
    Added the initial machine learning model created to predict respiratory system related diseases by reading SpO2 levels and the respiratory rate measured by the wearable.
    [bidmc_01_Breaths.csv, bidmc_01_Numerics.csv, bidmc_02_Breaths.csv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]
2026-06-29 Altium files
    PCB files
    [ESP32 Based.PrjPcb, PCB1.PcbDoc, Sheet2.SchDoc]
2026-07-01 Machine learning model
    Made changes to the machine learning model. The model runs locally on the computer by fetching data from the database and makes predictions and uploads the prediction back to firebase to be viewed on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
    [bidmc_01_Breaths.csv, bidmc_01_Numerics.csv, bidmc_02_Breaths.csv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]
